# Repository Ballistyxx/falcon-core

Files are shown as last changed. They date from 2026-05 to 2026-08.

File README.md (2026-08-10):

# Falcon Core

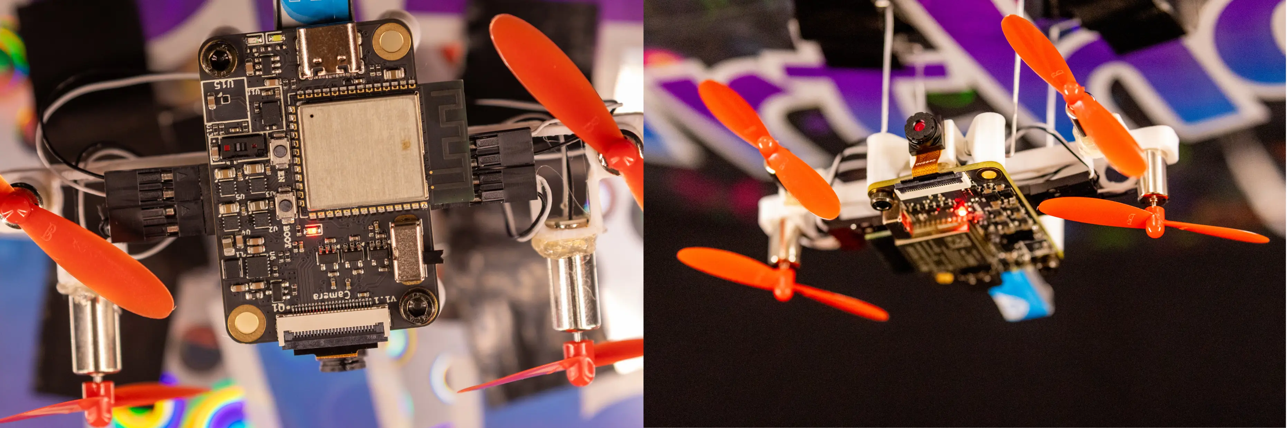
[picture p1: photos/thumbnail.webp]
Side-by-side images of the Falcon Core board


<!-- <table>
  <tr>
    <td><img src="photos/bottom-isometric-chassis.png" alt="Bottom isometric chassis" width="400"></td>
    <td><img src="photos/front-chassis.png" alt="Front chassis" width="400"></td>
  </tr>
</table> -->

A custom standalone ESP32-S3 flight controller for an indoor autonomous blimp. Successor to [Falcon Flight](https://github.com/PHS-SMCS/falcon-flight), redesigned from a Raspberry Pi Zero 2W HAT into a purpose-built 32×46mm 4-layer PCB.

Sponsored by [PCBWay](https://www.pcbway.com/).

## Specifications

- **MCU:** ESP32-S3-WROOM-1 (N8R8/N16R8) — dual-core LX7, Wi-Fi, BLE, 8MB PSRAM
- **Camera:** OV2640 via 24-pin 0.5mm FFC, 8-bit DVP interface
- **IMU:** BMI270 (6-axis accel/gyro, I2C)
- **Magnetometer:** MMC5633NJL (3-axis AMR, I2C, 1.62–3.6V)
- **ToF Sensor:** VL53L5CX (I2C)
- **Motor Drivers:** 4× DRV8212P bidirectional H-bridge
- **Battery Sensing:** Internal ADC (GPIO7)
- **Status LED:** Programmable red LED (GPIO48)
- **Board:** 32×46mm, 4-layer, matte black solder mask
- **Weight:** only 11 grams (excluding battery)

## Power

- **Battery:** BetaFPV 3.7V 300mAh 1S LiPo
- **Charging:** TP4057 via USB-C (5.1kΩ CC pull-downs)
- **Motor Power:** Direct battery feed to DRV8212P VM pins
- **Logic Isolation:** BLM18PG221SN1D ferrite bead between battery and logic rail
- **Regulators (ME6211 LDOs, SOT-23-5):**
  - 3.3V — ESP32-S3, sensors, VDDIO
  - 2.8V × 2 — OV2640 AVDD and DOVDD
  - 1.2V — OV2640 DVDD

## GPIO Assignment

| GPIO | Function |
|---|---|
| 1, 2 | SCCB (camera I2C — SIOD, SIOC) |
| 3 | M2_IN1 |
| 4 | M3_IN2 |
| 5 | M3_IN1 |
| 6 | M1_IN2 |
| 7 | BAT_ADC (battery voltage sensing) |
| 8, 18 | Main I2C bus (SDA, SCL) |
| 9, 10, 11, 12, 13, 14, 21, 40 | OV2640 DVP data bus (D8, D7, D6, D2, D5, D3, D4, D9) |
| 15 | M4_IN1 |
| 16 | M4_IN2 |
| 17 | M2_IN2 |
| 19, 20 | USB D−/D+ |
| 38 | Camera PCLK |
| 39 | Camera XCLK |
| 41 | HREF |
| 42 | VSYNC |
| 43, 44 | UART0 debug |
| 47 | M1_IN1 |
| 48 | Red LED (1kΩ to GND) |

Camera PWDN tied to GND, RESETB tied to 3.3V.

## I2C Bus

All sensors share the main I2C bus (GPIO8/18):

- BMI270 (accel/gyro)
- MMC5633NJL (magnetometer)
- VL53L5CX (time-of-flight)

Camera SCCB runs on a separate bus (GPIO1/2).

## Motor Layout

- 2× horizontal forward-facing motors (thrust)
- 1× downward-facing altitude motor (mounted below PCB on standoff)
- 1× TBD

## Firmware

Built with ESP-IDF. Custom PID stabilization (no ArduPilot). Communicates with a laptop over WebSocket for optical flow and AprilTag detection via OpenCV.

## License

See [LICENSE](LICENSE).

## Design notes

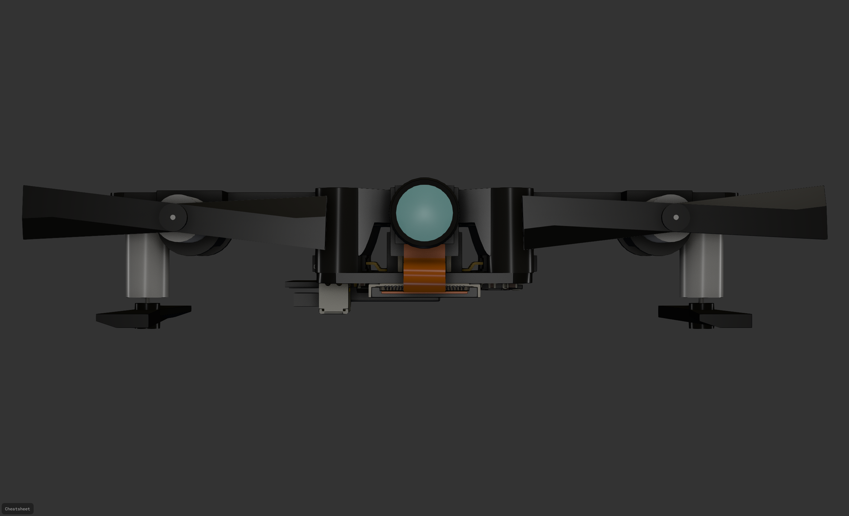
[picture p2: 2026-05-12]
photos/front-chassis.png

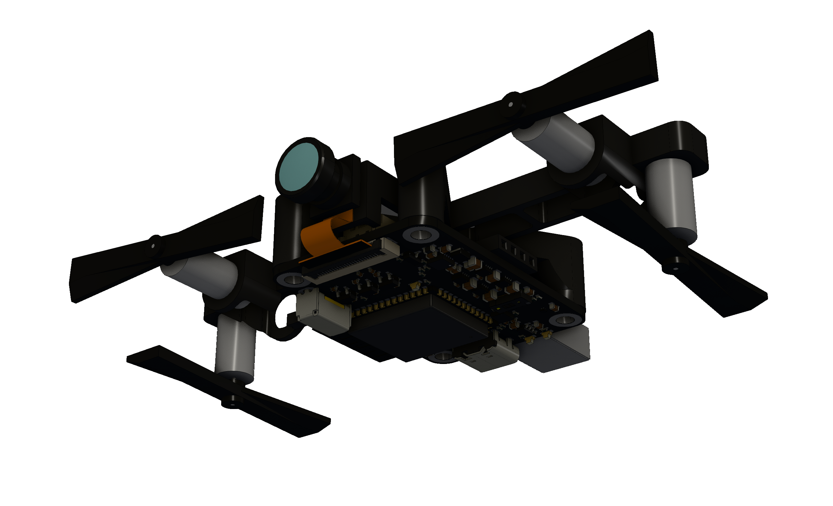
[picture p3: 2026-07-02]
photos/bottom-isometric-chassis.png

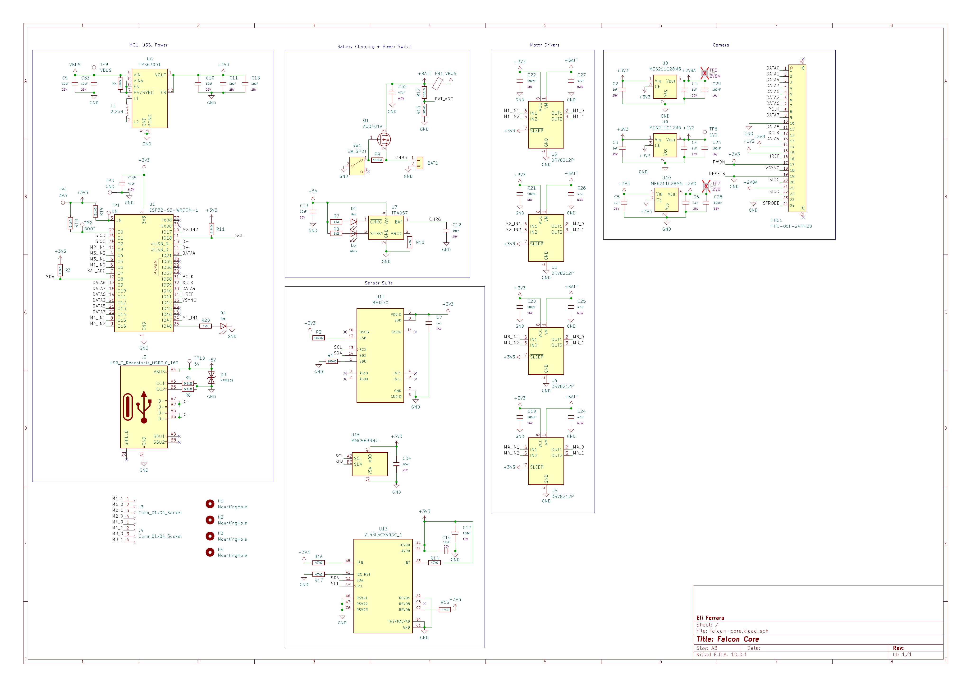
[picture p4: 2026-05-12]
PCB/schematic.png

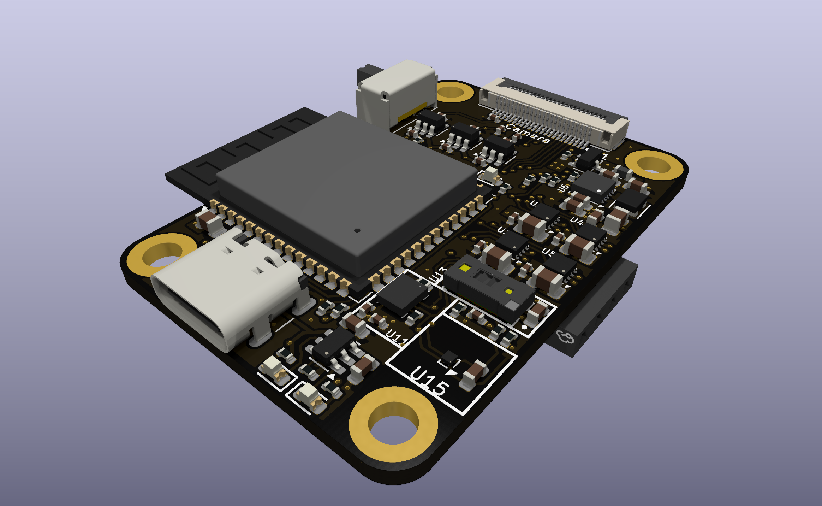
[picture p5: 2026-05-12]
photos/falcon-core.png

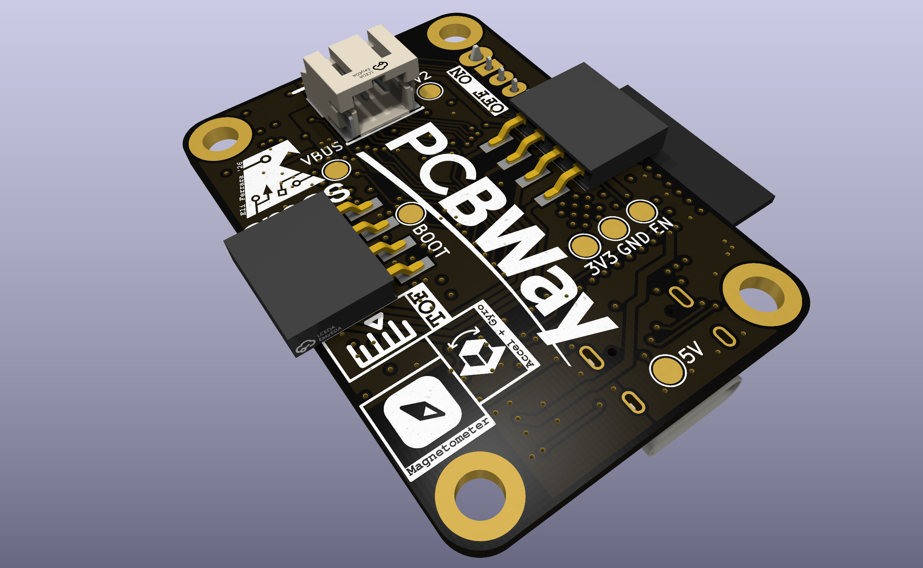
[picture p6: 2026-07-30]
photos/falcon-core-bottom-isometric.png

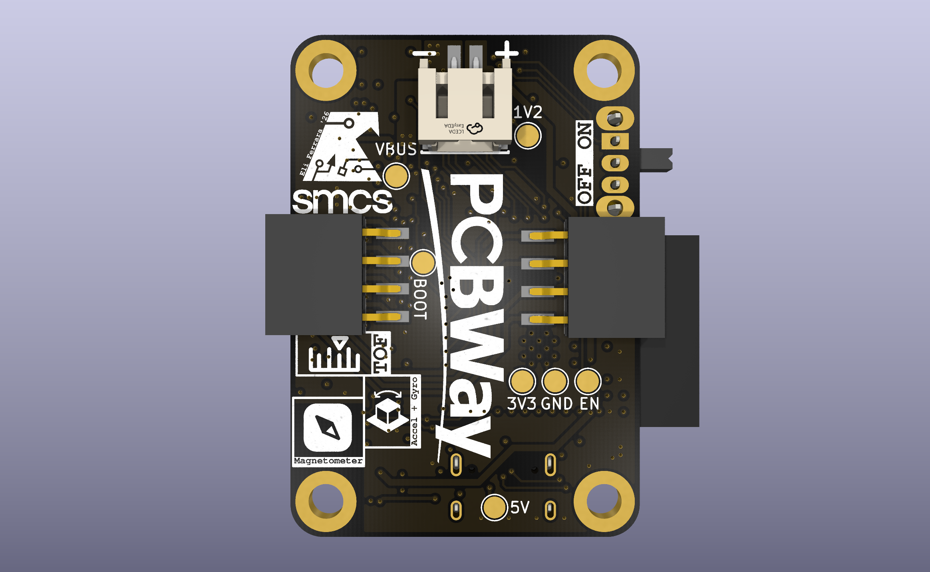
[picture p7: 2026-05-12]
photos/falcon-core-bottom.png

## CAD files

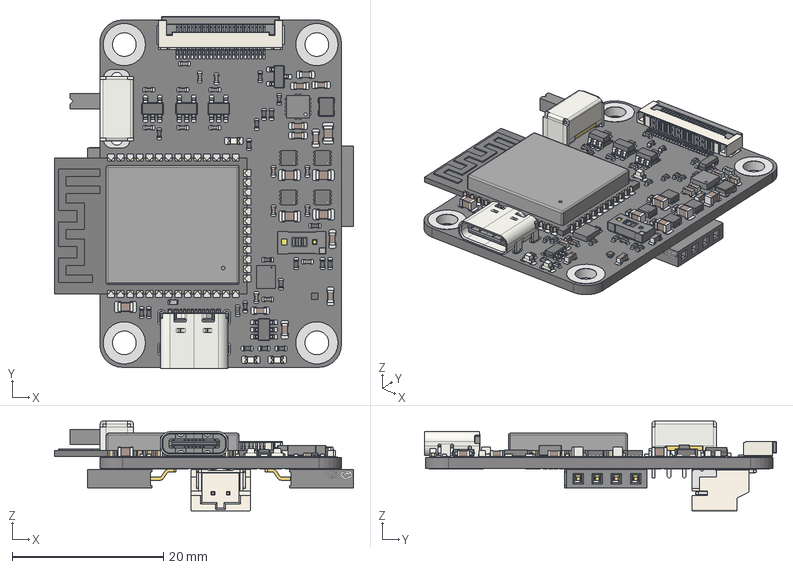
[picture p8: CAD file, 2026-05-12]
PCB/.step
39.6 x 46.7 x 11.9 mm
R_0402 x 20
SOT-23-5 x 3
C_0402 x 16
USB_C_Receptacle_GCT_USB4105-xx-A_16P_TopMnt_Horizontal
C_0805 x 6
TPS63001DRCR
C_0603 x 9
WSON-8-1EP_2x2mm_P0.5mm_EP0.9x1.6mm x 4
SOT-23
D_0603 x 3
BMI270_BOS
WLP-4_0.86x0.86mm_P0.4mm
FPC-SMD_24P-P0.50_FPC-05F-24PH20
VL53L5CXV0GC_1
ESP32-S3-WROOM-1
DFN1006-2L-RD
TSOT-23-6
SW_Slide_SPDT_Angled_CK_OS102011MA1Q
L_APV_ANR252010
L_0603_1608Metric
CONN-SMD_P2.00_S2B-PH-SM4-TB-LF-SN
CONN-SMD_4P-P2.54_HX-PM2.54-1X4PWT x 2
falcon-core_pad
falcon-core_PCB

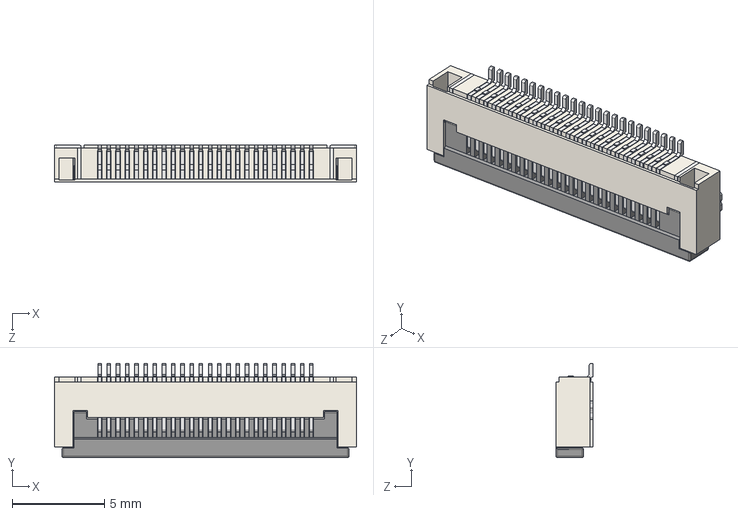
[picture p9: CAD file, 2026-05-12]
PCB/jlcpcb_lib/3dmodels/FPC-SMD_24P-P0.50_FPC-05F-24PH20.step
16.4 x 5.12 x 2.00 mm

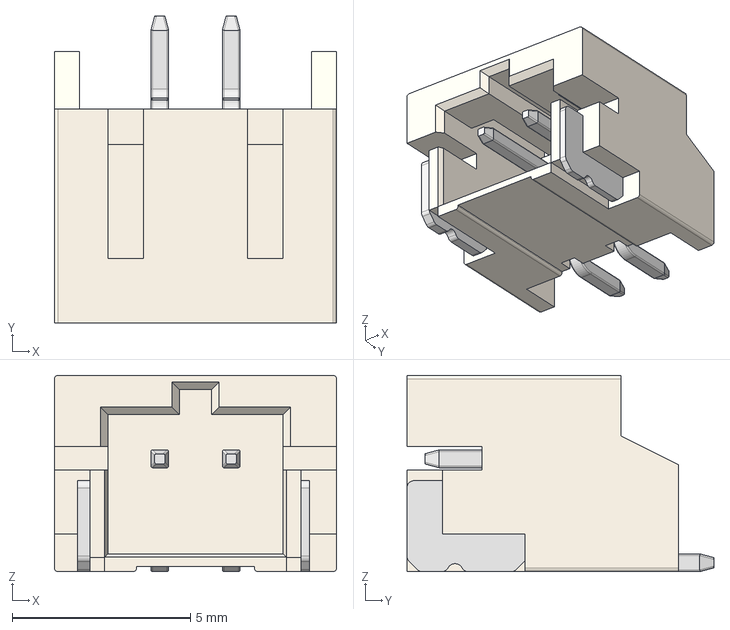
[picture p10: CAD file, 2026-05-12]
PCB/jlcpcb_lib/3dmodels/CONN-SMD_cleaned_v2.step
7.90 x 8.60 x 5.50 mm

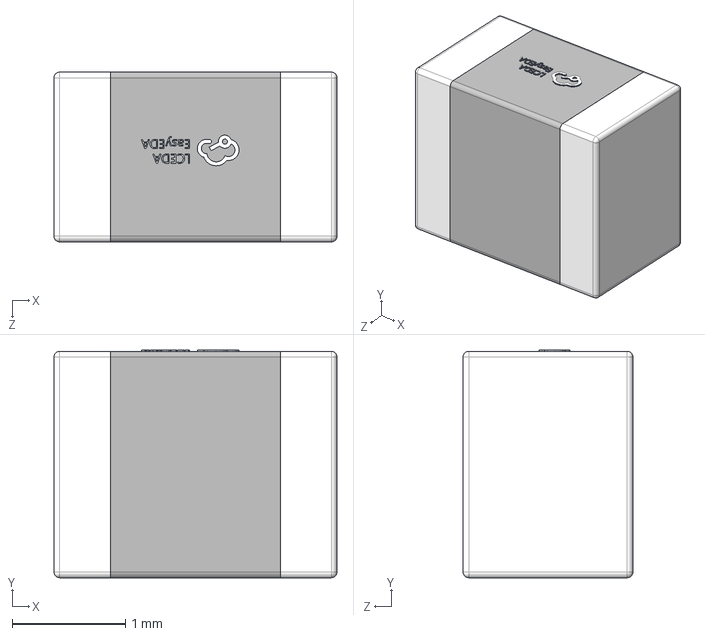
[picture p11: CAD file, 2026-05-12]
PCB/jlcpcb_lib/3dmodels/L1008.step
2.50 x 2.01 x 1.50 mm

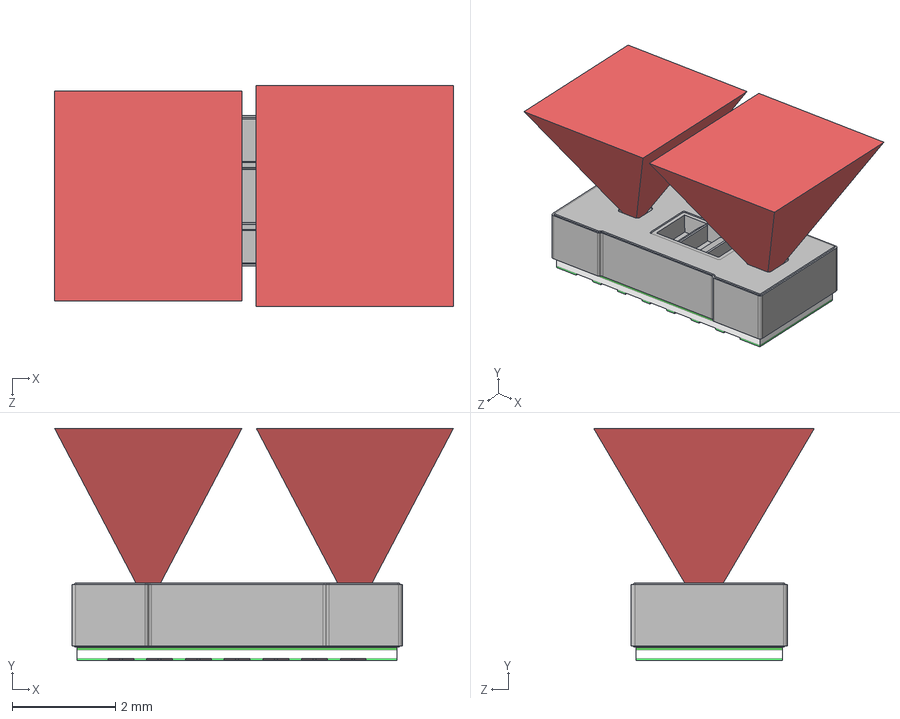
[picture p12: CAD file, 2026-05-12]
PCB/jlcpcb_lib/3dmodels/VL53L5 3D Model.step
7.72 x 4.50 x 4.28 mm
VL53L5 Module
VL53L5 Exclusion cones

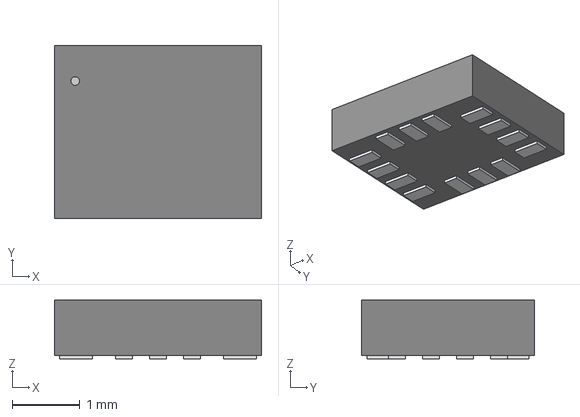
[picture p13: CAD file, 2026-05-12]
PCB/jlcpcb_lib/3dmodels/BMI270_BOS.step
3.05 x 2.54 x 0.866 mm

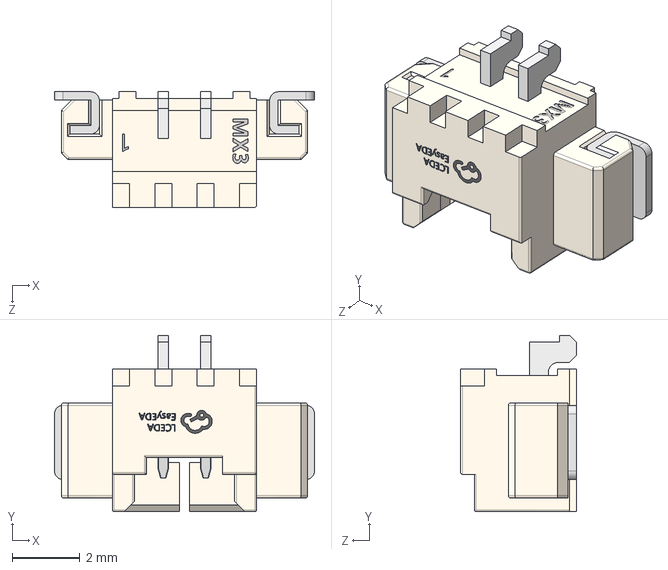
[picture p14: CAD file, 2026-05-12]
PCB/jlcpcb_lib/3dmodels/CONN-SMD_P1.25-H_1.25T-2PWT.step
7.65 x 5.19 x 3.40 mm

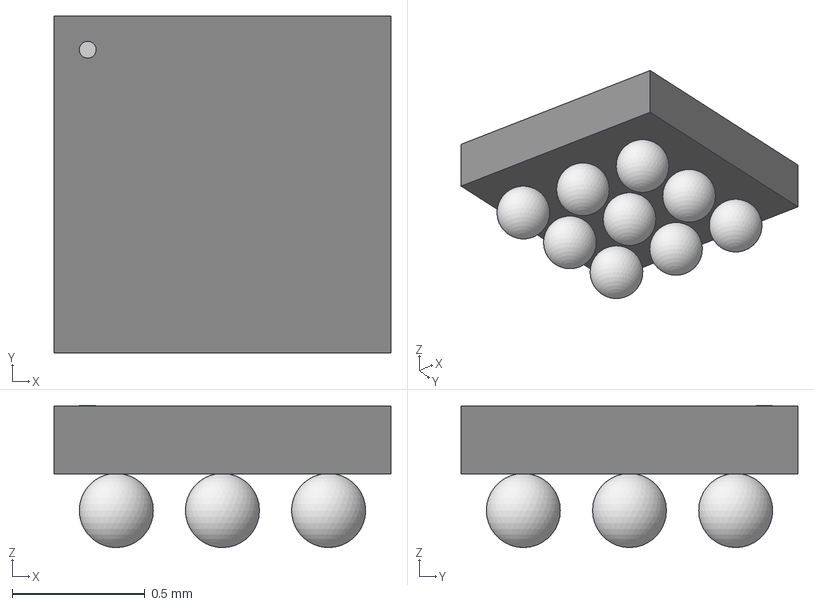
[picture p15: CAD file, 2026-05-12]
PCB/jlcpcb_lib/3dmodels/BGA9_BMM350_BOS.step
1.27 x 1.27 x 0.536 mm

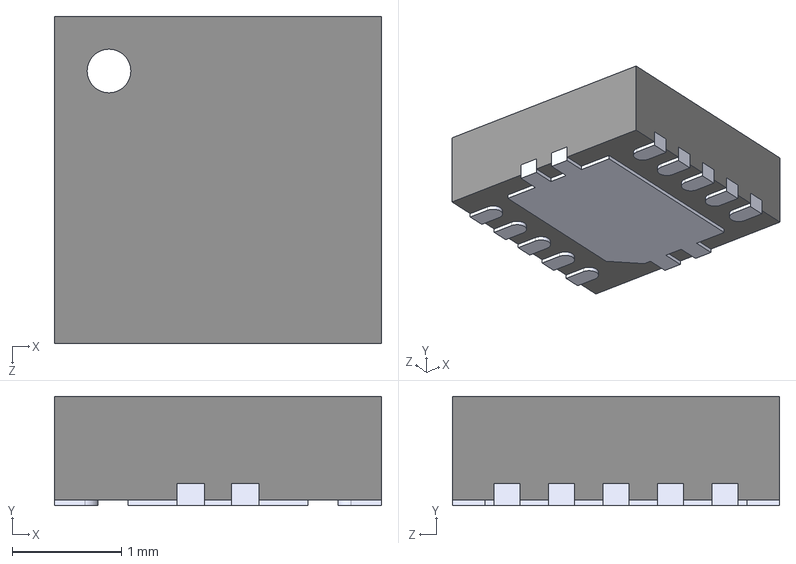
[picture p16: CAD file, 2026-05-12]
PCB/jlcpcb_lib/3dmodels/TPS63001DRCR.STEP
3.00 x 1.00 x 3.00 mm

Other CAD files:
PCB/jlcpcb_lib/3dmodels/CONN-SMD_P2.00_S2B-PH-SM4-TB-LF-SN.step

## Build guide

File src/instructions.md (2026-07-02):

# Falcon Core – Implementation Prompt

Build the firmware (ESP-IDF v5+, C) and web dashboard (HTML/CSS/JS, served locally) for an autonomous blimp flight controller. The ESP32-S3 streams camera video, reads sensors, runs motor control, and communicates with a laptop dashboard over WiFi. The dashboard provides live telemetry, a camera feed, and keyboard-based manual flight control.

---

## Hardware Overview

**MCU:** ESP32-S3-WROOM-1 (dual-core, 8MB flash, PSRAM via octal SPI)

**Confirmed GPIO Pinout:**

| Function | GPIO(s) | Notes |
|---|---|---|
| I2C SDA | IO8 | Shared bus: IMU, mag, ToF |
| I2C SCL | IO18 | |
| Camera SCCB SDA  | IO1 | Separate I2C for OV2640 config |
| Camera SCCB SCL  | IO2 | |
| Camera DVP data  | IO9(D8), IO10(D7), IO11(D6), IO12(D2), IO13(D5), IO14(D3), IO21(D4), IO40(D9) | |
| Camera HREF | IO41 | |
| Camera VSYNC | IO42 | |
| Camera PCLK | IO38 | |
| Camera XCLK | IO39 | Generate 20MHz via LEDC |
| Motor 1 IN1/IN2  | IO17 / IO6 | Horizontal left |
| Motor 2 IN1/IN2  | IO3 / IO47 | Horizontal right |
| Motor 3 IN1/IN2  | IO5 / IO4 | Vertical (altitude) |
| Motor 4 IN1/IN2  | IO15 / IO16 | Reserved (future use) |
| Battery ADC | IO7 | Resistive divider, ADC1 channel|
| Status LED | IO48 | Red LED, 1kΩ to GND |
| USB D-/D+ | IO19 / IO20 | USB-Serial-JTAG |
| UART0 TX/RX | IO43 / IO44 | Debug output |

**Motor Drivers:** 4× DRV8212P (bidirectional H-bridge). Each has IN1 and IN2 pins. PWM on IN1 with IN2 LOW = forward. PWM on IN2 with IN1 LOW = reverse. Both LOW = coast. Both HIGH = brake. Use ESP-IDF LEDC PWM at 20kHz.

**Sensors (all on shared I2C bus at IO8/IO18):**

| Sensor | Type | I2C Address | Key Details |
|---|---|---|---|
| BMI270 | 6-axis IMU | 0x68 | Accel + gyro. Requires config load on init. |
| MMC5633NJL | 3-axis magnetometer | 0x30 | SET/RESET for offset, continuous mode. |
| VL53L5CX | Multizone ToF | 0x29 | 8×8 ranging grid, I2C. Use ST's ULD driver. |

**Camera:** OV2640 via DVP (parallel interface). PWDN tied low, RESETB tied high. 24-pin 0.5mm FFC. Use `esp_camera` component from Espressif's registry.

---

## Firmware Architecture (ESP-IDF, C)

### WiFi

Connect in STA mode to a configured network (SSID/password stored in `sdkconfig` or hardcoded for now). Log the assigned IP address on boot so the user knows where to point the dashboard.

### HTTP + WebSocket Server

Use `esp_http_server`. Register these endpoints:

- `GET /stream` — MJPEG stream. Each connected client receives `multipart/x-mixed-replace` with boundary-delimited JPEG frames from the camera. Multiple simultaneous clients must be supported.
- `GET /ws` — WebSocket upgrade. Single endpoint for all bidirectional real-time data.

### WebSocket Protocol

Use JSON messages. Every message has a `"type"` field.

**ESP32 → Dashboard (telemetry, ~20Hz):**

```json
{
  "type": "telemetry",
  "ts": 123456,
  "imu": {
    "ax": 0.01, "ay": -0.02, "az": 9.78,
    "gx": 0.5, "gy": -0.3, "gz": 0.1
  },
  "mag": { "x": 25.3, "y": -10.1, "z": 42.0, "heading": 127.5 },
  "tof": { "distance_mm": 1200 },
  "battery": { "voltage": 3.85, "percent": 72 },
  "attitude": { "roll": 1.2, "pitch": -0.5, "yaw": 127.5 },
  "motors": { "m1": 0, "m2": 0, "m3": 0, "m4": 0 }
}
```

**Dashboard → ESP32 (commands):**

```json
{ "type": "motor_cmd", "m1": 0.5, "m2": 0.5, "m3": 0.0, "m4": 0.0 }
```

Motor values are floats from -1.0 (full reverse) to +1.0 (full forward). The firmware maps these to LEDC duty cycle and direction on IN1/IN2.

**Future extension:** A `"type": "velocity_cmd"` message will be added later for optical-flow-based velocity control. Design the command dispatch so new message types can be added without restructuring.

### FreeRTOS Tasks

| Task | Core | Priority | Rate | Description |
|---|---|---|---|---|
| `sensor_task` | 0 | 5 | 50Hz | Read BMI270 (accel+gyro) and MMC5633NJL (mag) via I2C. |
| `fusion_task` | 0 | 5 | 50Hz | Madgwick or complementary filter. Compute attitude + heading.  |
| `motor_task` | 0 | 6 | 50Hz | Read latest command from shared state, set LEDC duty cycles. |
| `tof_task` | 0 | 4 | 10Hz | Read VL53L5CX ranging data (center zone distance). |
| `battery_task` | 0 | 3 | 1Hz | Read ADC on IO7, compute voltage from divider ratio. |
| `camera_task` | 1 | 5 | — | Capture frames via `esp_camera`, push to frame buffer. |
| `telemetry_task` | 0 | 4 | 20Hz | Serialize shared state to JSON, send to all WS clients. |
| HTTP server | any  | 5 | event  | Handles `/stream` and `/ws`. Started once at init. |

### Shared State

A single struct protected by a FreeRTOS mutex. All tasks read/write through short critical sections (copy in, copy out).

```c
typedef struct {
    // Sensor data (written by sensor_task)
    float accel[3];
    float gyro[3];
    float mag[3];

    // Derived data (written by fusion_task)
    float roll, pitch, yaw;
    float heading_deg;

    // ToF (written by tof_task)
    uint16_t altitude_mm;

    // Battery (written by battery_task)
    float battery_voltage;
    uint8_t battery_percent;

    // Motor commands (written by WS receive handler)
    float motor_cmd[4];     // -1.0 to +1.0

    // Motor actual output (written by motor_task)
    float motor_output[4];
} falcon_state_t;
```

### Sensor Implementation Notes

**BMI270:** Requires a microcode config file upload after power-on before it produces data. The config binary is available from Bosch's BMI270 driver repo. Use burst I2C writes. After config, set accel to ±2g and gyro to ±500°/s at 100Hz ODR.

**MMC5633NJL:** Issue a SET then RESET command to initialize. Configure continuous measurement mode at 50Hz with auto SET/RESET enabled. Read XYZ registers. For now, heading = `atan2(y, x)` converted to degrees (tilt compensation will come later with fusion). Do not attempt calibration yet — just output raw values and heading.

**VL53L5CX:** Use ST's Ultra Lite Driver (ULD). Initialize, set resolution to 4×4 or 8×8, start ranging in continuous mode. For telemetry, report the center zone distance as altitude. The full zone grid will be used later.

**Battery ADC:** Use `adc_oneshot` API on ADC1. Apply the resistor divider ratio to convert raw reading to actual battery voltage. Map voltage to percentage using a simple linear approximation (3.0V = 0%, 4.2V = 100%).

### Motor Control

Initialize 4 LEDC channels at 20kHz. For each motor, two GPIO pins (IN1, IN2) map to forward and reverse:

```
if cmd > 0:  IN1 = PWM at |cmd| duty, IN2 = LOW   (forward)
if cmd < 0:  IN1 = LOW, IN2 = PWM at |cmd| duty    (reverse)
if cmd == 0: IN1 = LOW, IN2 = LOW                   (coast)
```

Duty cycle = `|cmd| * max_duty`. Clamp to a configurable maximum (start at 50% for safety during testing).

### Status LED

Blink patterns on IO48 to indicate state:
- Slow blink (1Hz): Connecting to WiFi
- Solid on: Connected, running
- Fast blink (5Hz): Error state

### sdkconfig.defaults

```
CONFIG_IDF_TARGET="esp32s3"
CONFIG_ESP_CONSOLE_USB_SERIAL_JTAG=y
CONFIG_ESPTOOLPY_FLASHMODE_DIO=y
CONFIG_ESPTOOLPY_FLASHFREQ_80M=y
CONFIG_ESPTOOLPY_FLASHSIZE_8MB=y
CONFIG_ESP_WIFI_SSID="Home-TMobile5g"
CONFIG_ESP_WIFI_PASSWORD="PSU4LIFE!"
CONFIG_HTTPD_MAX_REQ_HDR_LEN=1024
CONFIG_HTTPD_WS_SUPPORT=y
```

### Project Structure

```
src/
├── CMakeLists.txt
├── sdkconfig.defaults
├── main/
│   ├── CMakeLists.txt
│   ├── main.c              # app_main: init all subsystems, start tasks
│   ├── wifi.c / wifi.h      # STA connection, event handling
│   ├── server.c / server.h  # HTTP + WS server, MJPEG streaming
│   ├── camera.c / camera.h  # esp_camera init and frame capture
│   ├── sensors.c / sensors.h # BMI270, MMC5633NJL, VL53L5CX drivers
│   ├── fusion.c / fusion.h  # Attitude estimation (Madgwick filter)
│   ├── motors.c / motors.h  # LEDC PWM setup and motor command execution
│   ├── battery.c / battery.h # ADC reading, voltage/percent calculation
│   ├── state.c / state.h    # falcon_state_t definition, mutex helpers
│   └── led.c / led.h        # Status LED blink patterns
```

---

## Web Dashboard (HTML/CSS/JS)

A single `index.html` file served locally on the laptop (not from the ESP32). It connects to the blimp over the local network.

### Connection

On load, prompt for or use a hardcoded blimp IP. Open:
- WebSocket to `ws://<ip>/ws` for telemetry and commands.
- `<img>` tag with `src="http://<ip>/stream"` for the MJPEG video feed.

### Layout

A single-page dashboard with these sections:

1. **Camera feed** — large, dominant. The MJPEG `<img>` element. Aspect ratio 4:3 or 16:9 depending on camera resolution.

2. **Compass** — a circular compass rose rendered in SVG or canvas. The needle rotates to show `heading_deg` from telemetry. Display heading in degrees numerically below it. Cardinal directions (N/S/E/W) labeled around the ring.

3. **Attitude indicator** — show roll and pitch visually (an artificial horizon or simple tilt bars). Yaw can share the compass.

4. **Sensor readouts** — a panel showing:
   - Battery voltage and percentage (with a colored bar: green > 50%, yellow 20-50%, red < 20%)
   - Altitude (ToF distance in mm or cm)
   - Raw accelerometer XYZ
   - Raw gyroscope XYZ
   - Raw magnetometer XYZ
   - Motor outputs M1–M4 (as bars or values)

5. **Connection status** — indicator showing WebSocket state (connected/disconnected/reconnecting).

6. **Controls legend** — small reference showing the WASD/QE key bindings.

### Keyboard Controls (WASD/QE)

Capture `keydown` and `keyup` events. While a key is held, send the corresponding motor command at 10Hz. On key release, send zero for that axis.

**Key mapping (differential thrust for translation + yaw):**

| Key | Action | Motor effect |
|-----|---|---|
| W | Forward | M1 = +throttle, M2 = +throttle (both horizontal fwd)  |
| S | Backward | M1 = -throttle, M2 = -throttle (both horizontal rev)  |
| A | Yaw left | M1 = -throttle, M2 = +throttle (differential) |
| D | Yaw right | M1 = +throttle, M2 = -throttle (differential) |
| Q | Descend | M3 = -throttle (vertical motor down) |
| E | Ascend | M3 = +throttle (vertical motor up) |

Throttle magnitude is a fixed value (start at 0.4). Multiple keys can be held simultaneously — sum the contributions per motor and clamp to [-1, 1]. M4 is always 0 for now.

Send commands as: `{ "type": "motor_cmd", "m1": 0.4, "m2": 0.4, "m3": 0.0, "m4": 0.0 }`

When no keys are held, send `{ "type": "motor_cmd", "m1": 0, "m2": 0, "m3": 0, "m4": 0 }` once, then stop sending.

### Telemetry Handling

Parse incoming `"type": "telemetry"` messages. Update all dashboard elements at the rate they arrive (~20Hz). Use `requestAnimationFrame` for smooth compass/attitude animation. Display a "stale data" warning if no telemetry arrives for >2 seconds.

### Reconnection

If the WebSocket drops, attempt reconnection every 3 seconds. Show connection state in the status indicator. The MJPEG `<img>` will stall on disconnect — provide a reload button or auto-retry via `onerror`.

### Styling

Dark theme. Monospace font for numeric readouts. The dashboard should be functional and readable, not flashy. Minimal dependencies — vanilla JS, no frameworks. CSS grid or flexbox for layout.

---

## What NOT to Implement Yet

- Optical flow (will be a separate Python script connecting to the same WebSocket later)
- Magnetometer calibration (raw values only for now)
- Tilt-compensated heading (use simple atan2 for now)
- Autonomous flight modes
- PID controllers
- AprilTag detection
- NVS storage for calibration data
- OTA firmware updates

Design all interfaces (WebSocket protocol, shared state struct, task architecture) so these can be added without restructuring existing code.

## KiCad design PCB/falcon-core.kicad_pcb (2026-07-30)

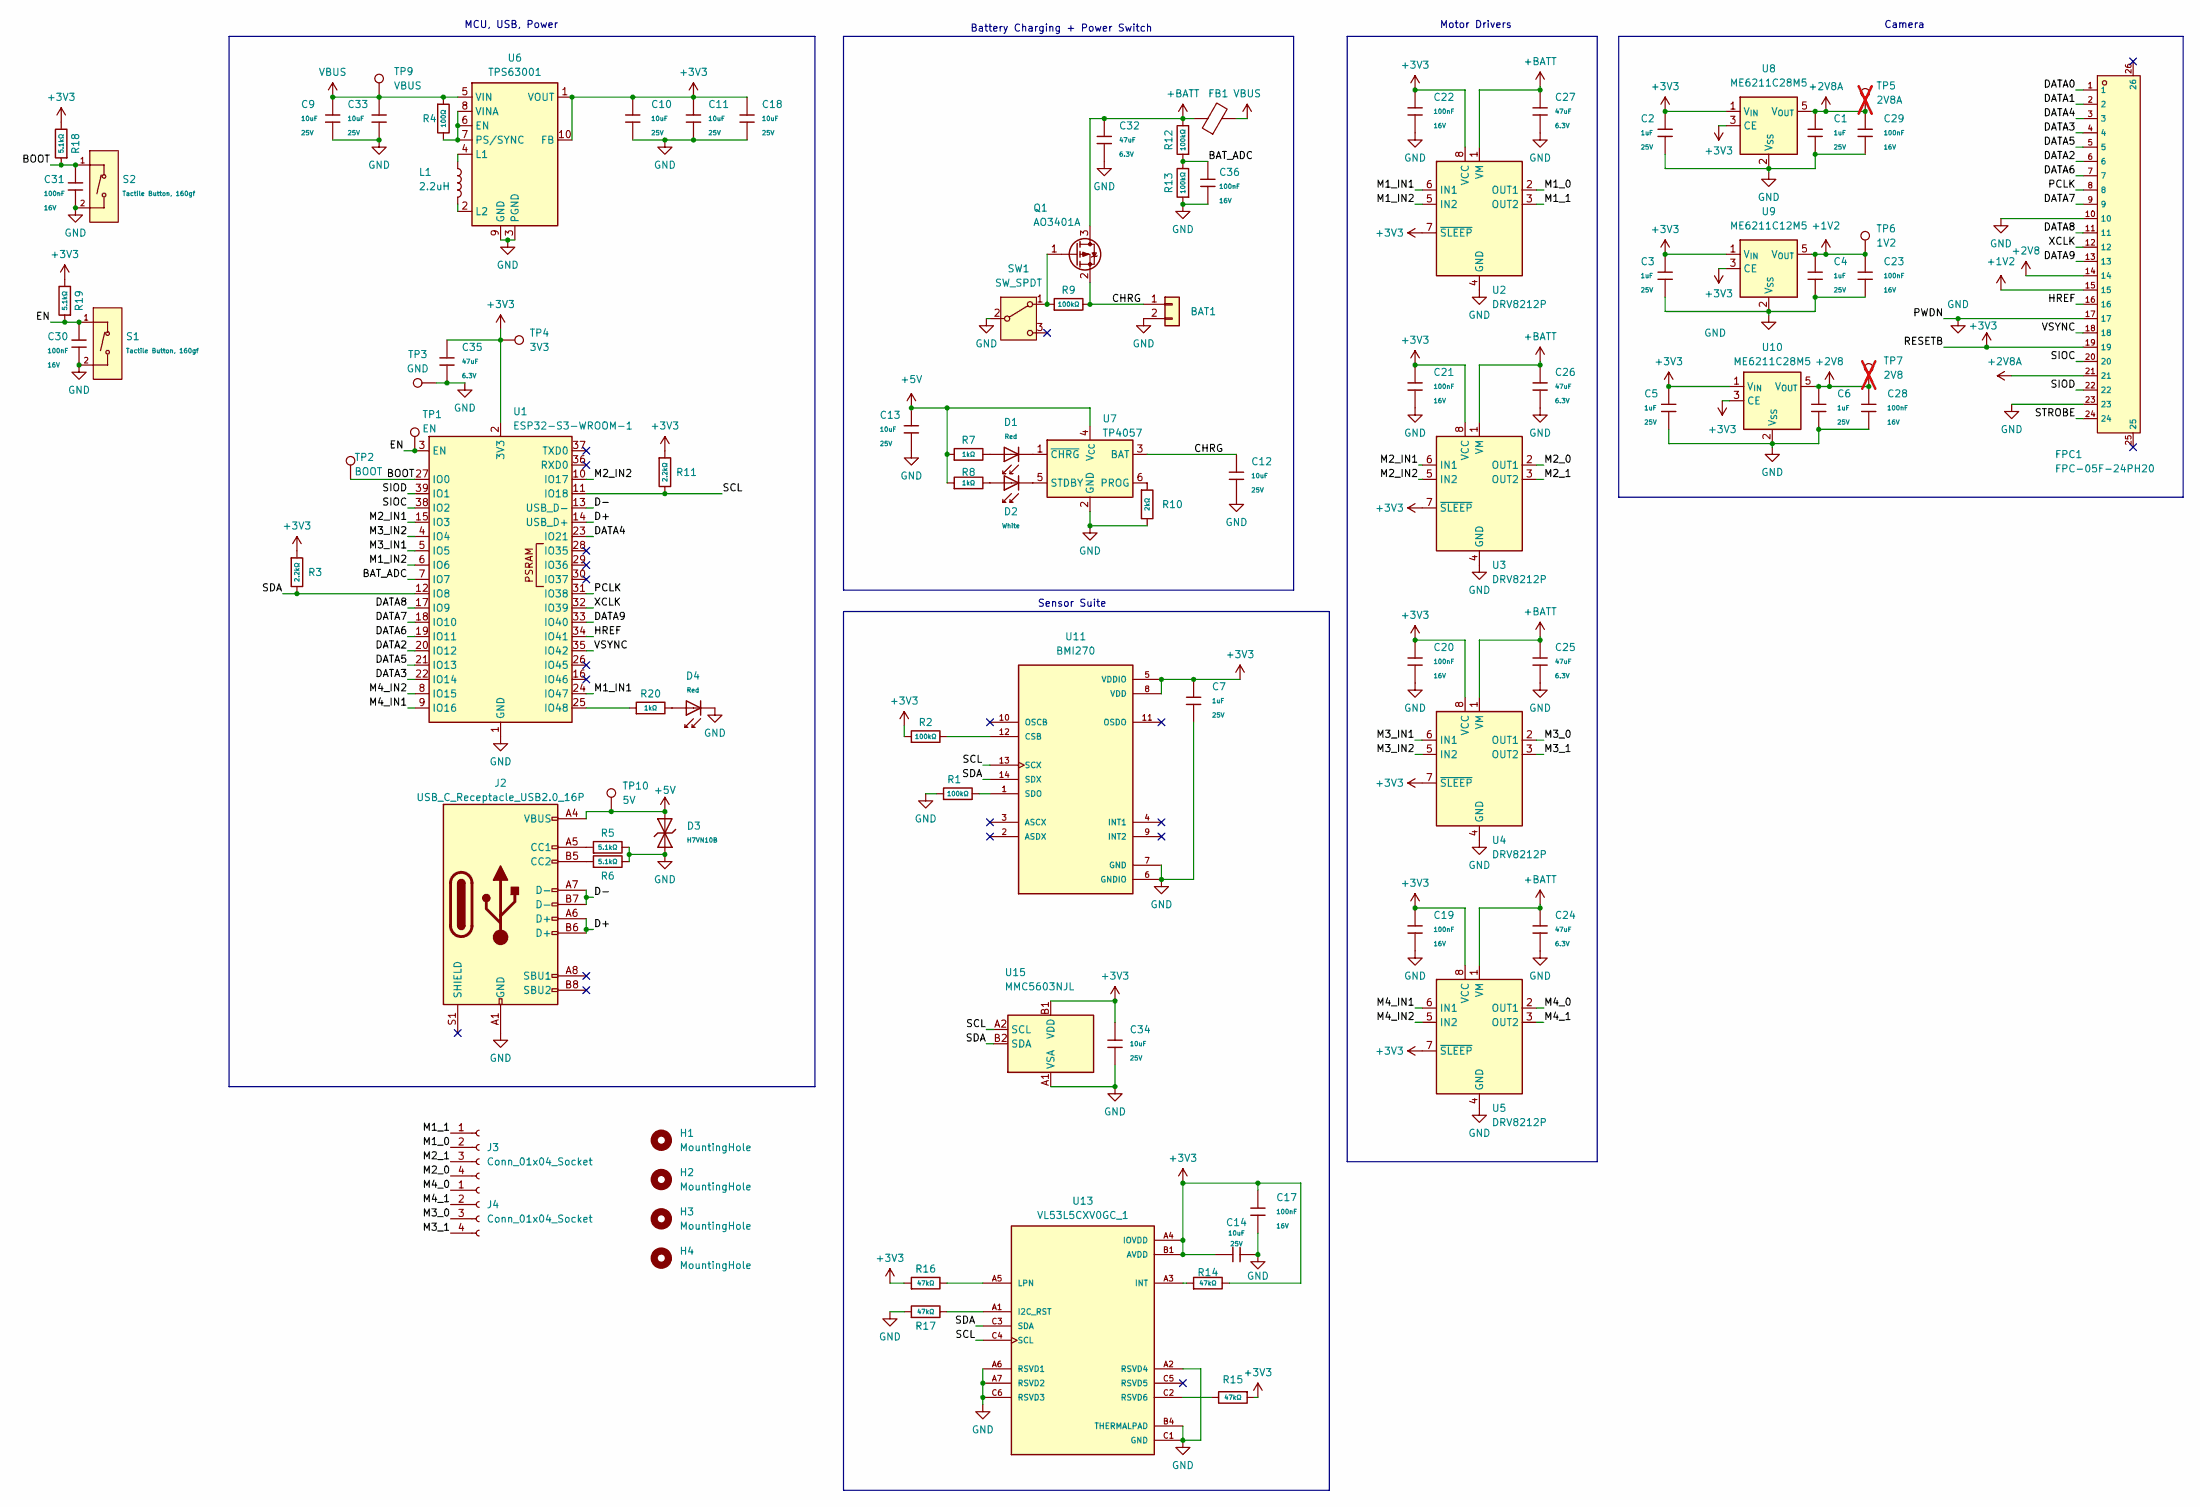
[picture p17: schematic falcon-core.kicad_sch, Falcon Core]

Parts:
BAT1: Conn_01x02; CONN-SMD_2P-P2.00_WF-1F200A2P; LCSC C23397052
C1, C2, C3, C4, C5, C6, C7: 1uF; C_0402; Voltage Rated 25V; Tolerance ±10%; Part CL05A105KA5NQNC; LCSC C52923
C9, C10, C11, C12, C13, C14, C18, C33, C34: 10uF; C_0603; Voltage Rated 25V; Tolerance ±20%; Part CL10A106MA8NRNC; LCSC C96446
C17, C19, C20, C21, C22, C23, C28, C29, C30, C31, C36: 100nF; C_0402; Voltage Rated 16V; Tolerance ±10%; Part CL05B104KO5NNNC; LCSC C1525
C24, C25, C26, C27, C32, C35: 47uF; C_0805; Voltage Rated 6.3V; Tolerance ±20%; Part CL21A476MQYNNNE; LCSC C16780
D1, D4: Red; D_0603; Part KT-0603R; LCSC C2286
D2: White; D_0603; Part KT-0603W; LCSC C2290
D3: H7VN10B; D_DFN1006-2L; Part H7VN10B; LCSC C20615788
FB1: FerriteBead; L_0603_1608Metric; LCSC Part Number C80165
FPC1: FPC-05F-24PH20; FPC-SMD_24P-P0.50_FPC-05F-24PH20; LCSC C2856805
H1, H2, H3, H4: MountingHole; MountingHole_3.2mm_M3_DIN965_Pad
J2: USB_C_Receptacle_USB2.0_16P; USB_C_Receptacle_GCT_USB4105-xx-A_16P_TopMnt_Horizontal; LCSC C393939
J3, J4: Conn_01x04_Socket; CONN-SMD_4P-P2.54_HX-PM2.54-1X4PWT; LCSC C46061768
L1: 2.2uH; L_APV_ANR252010; LCSC C5349606
Q1: AO3401A; SOT-23; LCSC C15127
R1, R2, R9, R12, R13: 100kΩ; R_0402; Overload Voltage (Max) 50V; Tolerance ±1%; Part 0402WGF1003TCE; LCSC C25741
R3, R11: 2.2kΩ; R_0402; Overload Voltage (Max) 50V; Tolerance ±1%; Part 0402WGF2201TCE; LCSC C25879
R4: 100Ω; R_0402; Overload Voltage (Max) 50V; Tolerance ±1%; Part 0402WGF1000TCE; LCSC C25076
R5, R6, R18, R19: 5.1kΩ; R_0402; Overload Voltage (Max) 50V; Tolerance ±1%; Part 0402WGF5101TCE; LCSC C25905
R7, R8, R20: 1kΩ; R_0402; Overload Voltage (Max) 50V; Tolerance ±1%; Part 0402WGF1001TCE; LCSC C11702
R10: 2kΩ; R_0402; Overload Voltage (Max) 50V; Tolerance ±1%; Part 0402WGF2001TCE; LCSC C4109
R14, R15, R16, R17: 47kΩ; R_0402; Overload Voltage (Max) 50V; Tolerance ±1%; Part 0402WGF4702TCE; LCSC C25792
S1, S2: Tactile Button, 160gf; SW_TS-1088-AR02016; Voltage Rating (Dc) 12V; Part TS-1088-AR02016; LCSC C720477
SW1: SW_SPDT; SW_Slide_SPDT_Angled_CK_OS102011MA1Q; LCSC C431547
TP1: EN; TestPoint_Pad_D2.0mm
TP2: BOOT; TestPoint_Pad_D2.0mm
TP3: GND; TestPoint_Pad_D2.0mm
TP4: 3V3; TestPoint_Pad_D2.0mm
TP5: 2V8A; TestPoint_Pad_D2.0mm; not fitted
TP6: 1V2; TestPoint_Pad_D2.0mm
TP7: 2V8; TestPoint_Pad_D2.0mm; not fitted
TP9: VBUS; TestPoint_Pad_D2.0mm
TP10: 5V; TestPoint_Pad_D2.0mm
U1: ESP32-S3-WROOM-1; LCSC C2913202
U2, U3, U4, U5: DRV8212P; WSON-8-1EP_2x2mm_P0.5mm_EP0.9x1.6mm_ThermalVias; LCSC C5208051
U6: TPS63001; Texas_DRC0010J_ThermalVias; LCSC C28060
U7: TP4057; TSOT-23-6; LCSC C12044
U8, U10: ME6211C28M5; SOT-23-5; LCSC C53099
U9: ME6211C12M5; SOT-23-5; LCSC C236672
U11: BMI270; XDCR_BMI270; LCSC C2836813
U13: VL53L5CXV0GC_1; XDCR_VL53L5CXV0GC_1; PARTREV 13; LCSC C3178303
U15: MMC5603NJL; WLP-4_0.86x0.86mm_P0.4mm; LCSC C404328

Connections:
+1V2: C4.1, C23.2, FPC1.15, TP6.1 (1_1), U9.5 (V_{OUT})
+2V8: C6.1, C28.2, FPC1.14, TP7.1, U10.5 (V_{OUT})
+2V8A: C1.1, C29.2, FPC1.21, TP5.1, U8.5 (V_{OUT})
+5V: C13.1, D3.2, J2.A4 (VBUS), J2.A9 (VBUS), J2.B4 (VBUS), J2.B9 (VBUS), R7.1, R8.1, TP10.1 (1_1), U7.4 (V_{CC})
+BATT: C24.1, C25.1, C26.1, C27.1, C32.1, FB1.1, Q1.3 (D), R12.2, U2.1 (VM), U3.1 (VM), U4.1 (VM), U5.1 (VM)
/BAT_ADC: C36.1, R12.1, R13.2, U1.7 (IO7)
/BOOT: C31.1, R18.1, S2.1 (A), TP2.1 (1_1), U1.27 (IO0)
/CHRG: BAT1.1, C12.1, Q1.2 (S), R9.2, U7.3 (BAT)
/D+: J2.A6 (D+), J2.B6 (D+), U1.14 (USB_D+)
/D-: J2.A7 (D-), J2.B7 (D-), U1.13 (USB_D-)
/DATA0: FPC1.1
/DATA1: FPC1.2
/DATA2: FPC1.6, U1.20 (IO12)
/DATA3: FPC1.4, U1.22 (IO14)
/DATA4: FPC1.3, U1.23 (IO21)
/DATA5: FPC1.5, U1.21 (IO13)
/DATA6: FPC1.7, U1.19 (IO11)
/DATA7: FPC1.9, U1.18 (IO10)
/DATA8: FPC1.11, U1.17 (IO9)
/DATA9: FPC1.13, U1.33 (IO40)
/HREF: FPC1.16, U1.34 (IO41)
/M1_0: J3.2, U2.2 (OUT1)
/M1_1: J3.1, U2.3 (OUT2)
/M1_IN1: U1.24 (IO47), U2.6 (IN1)
/M1_IN2: U1.6 (IO6), U2.5 (IN2)
/M2_0: J3.4, U3.2 (OUT1)
/M2_1: J3.3, U3.3 (OUT2)
/M2_IN1: U1.15 (IO3), U3.6 (IN1)
/M2_IN2: U1.10 (IO17), U3.5 (IN2)
/M3_0: J4.3, U4.2 (OUT1)
/M3_1: J4.4, U4.3 (OUT2)
/M3_IN1: U1.5 (IO5), U4.6 (IN1)
/M3_IN2: U1.4 (IO4), U4.5 (IN2)
/M4_0: J4.1, U5.2 (OUT1)
/M4_1: J4.2, U5.3 (OUT2)
/M4_IN1: U1.9 (IO16), U5.6 (IN1)
/M4_IN2: U1.8 (IO15), U5.5 (IN2)
/PCLK: FPC1.8, U1.31 (IO38)
/SCL: R11.2, U1.11 (IO18), U11.13 (SCX), U13.C4 (SCL), U15.A2 (SCL)
/SDA: R3.2, U1.12 (IO8), U11.14 (SDX), U13.C3 (SDA), U15.B2 (SDA)
/SIOC: FPC1.20, U1.38 (IO2)
/SIOD: FPC1.22, U1.39 (IO1)
/STROBE: FPC1.24
/VSYNC: FPC1.18, U1.35 (IO42)
/XCLK: FPC1.12, U1.32 (IO39)
GND: BAT1.2, C1.2, C2.2, C3.2, C4.2, C5.2, C6.2, C7.2, C9.2, C10.2, C11.2, C12.2, C13.2, C14.2, C17.2, C18.2, C19.1, C20.1, C21.1, C22.1, C23.1, C24.2, C25.2, C26.2, C27.2, C28.1, C29.1, C30.2, C31.2, C32.2, C33.2, C34.1, C35.2, C36.2, D3.1, D4.1, FPC1.10, FPC1.17, FPC1.23, J2.A1 (GND), J2.A12 (GND), J2.B1 (GND), J2.B12 (GND), R1.1, R5.2, R6.2, R10.2, R13.1, R17.1, S1.2 (B), S2.2 (B), SW1.2 (B), TP3.1 (1_1), U1.1 (GND), U1.40 (GND), U1.41 (GND), U2.4 (GND), U2.9 (GND), U3.4 (GND), U3.9 (GND), U4.4 (GND), U4.9 (GND), U5.4 (GND), U5.9 (GND), U6.3 (PGND), U6.9 (GND), U6.11 (PGND), U7.2 (GND), U8.2 (V_{SS}), U9.2 (V_{SS}), U10.2 (V_{SS}), U11.6 (GNDIO), U11.7 (GND), U13.A2 (RSVD4), U13.A6 (RSVD1), U13.A7 (RSVD2), U13.B4 (THERMALPAD), U13.C1 (GND), U13.C6 (RSVD3), U13.C7 (GND), U15.A1 (VSA); also elsewhere on the board
unnamed: D1.2, R7.2
unnamed: D2.2, R8.2
unnamed: D4.2, R20.2
unnamed: J2.A5 (CC1), R5.1
unnamed: J2.B5 (CC2), R6.1
unnamed: Q1.1 (G), R9.1, SW1.1 (A)
unnamed: R20.1, U1.25 (IO48)
unnamed: R4.2, U6.6 (EN), U6.7 (PS/SYNC), U6.8 (VINA)
unnamed: L1.1, U6.4 (L1)
unnamed: L1.2, U6.2 (L2)
unnamed: R10.1, U7.6 (PROG)
unnamed: D2.1, U7.5 (STDBY)
unnamed: D1.1, U7.1 (~CHRG)
unnamed: R2.2, U11.12 (CSB)
unnamed: R1.2, U11.1 (SDO)
unnamed: R17.2, U13.A1 (I2C_RST)
unnamed: R14.1, U13.A3 (INT)
unnamed: R16.2, U13.A5 (LPN)
unnamed: R15.2, U13.C2 (RSVD6)
VBUS: C9.1, C33.1, FB1.2, R4.1, TP9.1 (1_1), U6.5 (VIN)

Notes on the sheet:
Battery Charging + Power Switch
Sensor Suite
MCU, USB, Power
Camera
Motor Drivers

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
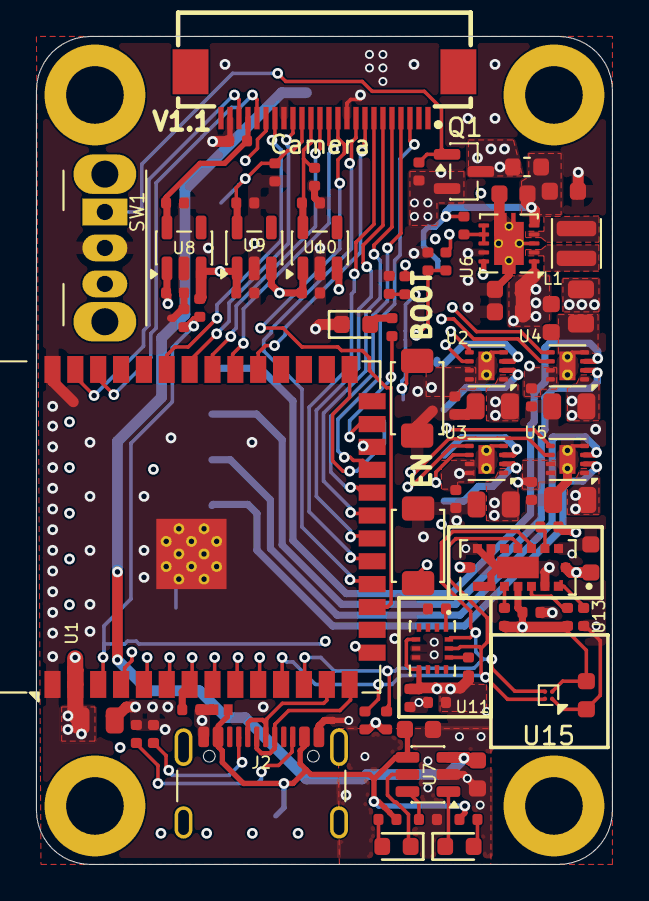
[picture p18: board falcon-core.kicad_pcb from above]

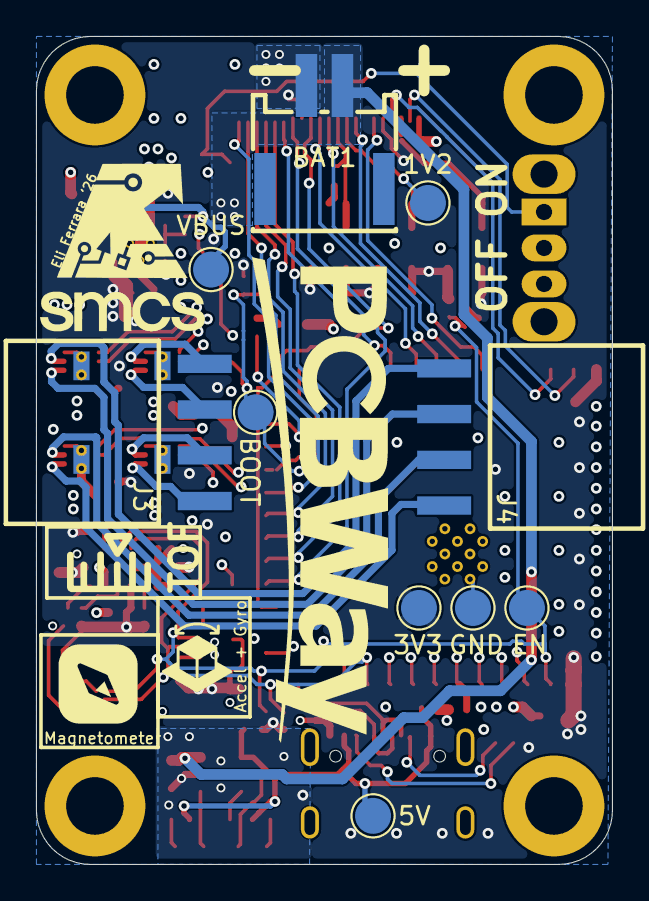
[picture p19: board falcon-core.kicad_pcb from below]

Board: 4 copper layers, 32.0 x 46.0 mm, 93 parts (10 on the bottom side), 65 nets.

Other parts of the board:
C30#2: 100nF; C_0402

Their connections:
GND: C30#2.2; also elsewhere on the board

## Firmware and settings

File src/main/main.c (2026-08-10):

/*
 * Falcon Core – autonomous blimp flight controller firmware.
 *
 * app_main brings up every subsystem then launches the FreeRTOS task set that
 * reads sensors, fuses attitude, drives motors, and streams telemetry/video to
 * the laptop dashboard over WiFi.
 */

#include <stdio.h>
#include <string.h>
#include "freertos/FreeRTOS.h"
#include "freertos/task.h"
#include "esp_log.h"
#include "esp_timer.h"
#include "nvs_flash.h"

#include "state.h"
#include "led.h"
#include "wifi.h"
#include "motors.h"
#include "battery.h"
#include "sensors.h"
#include "fusion.h"
#include "magcal.h"
#include "camera.h"
#include "server.h"

static const char *TAG = "falcon";

/* ---- Periodic tasks ----------------------------------------------------- */

static void sensor_task(void *arg)   /* core 0, 50 Hz */
{
    (void)arg;
    TickType_t last = xTaskGetTickCount();
    float accel[3], gyro[3], mag[3];
    while (1) {
        if (sensors_read_imu(accel, gyro)) {
            state_set_imu(accel, gyro);
        }
        if (sensors_read_mag(mag)) {
            state_set_mag(mag);
        }
        vTaskDelayUntil(&last, pdMS_TO_TICKS(20));
    }
}

static void fusion_task(void *arg)   /* core 0, 50 Hz */
{
    (void)arg;
    const float dt = 0.02f;
    TickType_t last = xTaskGetTickCount();
    while (1) {
        falcon_state_t s;
        state_snapshot(&s);
        /* Heading uses the calibrated magnetometer; telemetry still reports the
         * raw vector so the dashboard can (re)compute calibration from it. */
        float mag_cal[3];
        magcal_apply(s.mag, mag_cal);
        float roll, pitch, yaw, heading;
        fusion_update(s.accel, s.gyro, mag_cal, dt, &roll, &pitch, &yaw, &heading);
        state_set_attitude(roll, pitch, yaw, heading);
        vTaskDelayUntil(&last, pdMS_TO_TICKS(20));
    }
}

static void motor_task(void *arg)    /* core 0, 50 Hz */
{
    (void)arg;
    TickType_t last = xTaskGetTickCount();
    while (1) {
        float cmd[4], out[4];
        state_get_motor_cmd(cmd);
        motors_apply(cmd, out);
        state_set_motor_output(out);
        vTaskDelayUntil(&last, pdMS_TO_TICKS(20));
    }
}

static void tof_task(void *arg)      /* core 0, 10 Hz */
{
    (void)arg;
    TickType_t last = xTaskGetTickCount();
    while (1) {
        uint16_t mm;
        uint16_t grid[TOF_GRID_ZONES];
        if (sensors_read_tof(&mm, grid)) {
            state_set_tof(mm, grid);
        }
        vTaskDelayUntil(&last, pdMS_TO_TICKS(100));
    }
}

static void battery_task(void *arg)  /* core 0, 1 Hz */
{
    (void)arg;
    TickType_t last = xTaskGetTickCount();
    while (1) {
        float v;
        uint8_t pct;
        battery_read(&v, &pct);
        state_set_battery(v, pct);
        vTaskDelayUntil(&last, pdMS_TO_TICKS(1000));
    }
}

static void telemetry_task(void *arg)  /* core 0, 20 Hz */
{
    (void)arg;
    static char json[1400];
    TickType_t last = xTaskGetTickCount();
    while (1) {
        falcon_state_t s;
        state_snapshot(&s);
        magcal_t mc;
        magcal_get(&mc);
        uint32_t ts = (uint32_t)(esp_timer_get_time() / 1000);

        /* Flatten the 8x8 ToF grid into a JSON array (row-major, mm).
         * 64 zones × up to 5 chars ("4000,") plus brackets and NUL. */
        char grid_str[352];
        int gp = 0;
        grid_str[gp++] = '[';
        for (int i = 0; i < TOF_GRID_ZONES; i++) {
            gp += snprintf(grid_str + gp, sizeof(grid_str) - gp,
                           "%s%u", i ? "," : "", s.tof_grid[i]);
        }
        grid_str[gp++] = ']';
        grid_str[gp] = '\0';

        int n = snprintf(json, sizeof(json),
            "{\"type\":\"telemetry\",\"ts\":%lu,"
            "\"imu\":{\"ax\":%.3f,\"ay\":%.3f,\"az\":%.3f,"
            "\"gx\":%.3f,\"gy\":%.3f,\"gz\":%.3f},"
            "\"mag\":{\"x\":%.2f,\"y\":%.2f,\"z\":%.2f,\"heading\":%.1f},"
            "\"magcal\":{\"ox\":%.2f,\"oy\":%.2f,\"oz\":%.2f,"
            "\"sx\":%.4f,\"sy\":%.4f,\"sz\":%.4f},"
            "\"tof\":{\"distance_mm\":%u,\"grid\":%s},"
            "\"battery\":{\"voltage\":%.3f,\"percent\":%u},"
            "\"wifi\":{\"rssi\":%d},"
            "\"attitude\":{\"roll\":%.1f,\"pitch\":%.1f,\"yaw\":%.1f},"
            "\"motors\":{\"m1\":%.2f,\"m2\":%.2f,\"m3\":%.2f,\"m4\":%.2f}}",
            (unsigned long)ts,
            s.accel[0], s.accel[1], s.accel[2],
            s.gyro[0], s.gyro[1], s.gyro[2],
            s.mag[0], s.mag[1], s.mag[2], s.heading_deg,
            mc.offset[0], mc.offset[1], mc.offset[2],
            mc.scale[0], mc.scale[1], mc.scale[2],
            s.altitude_mm, grid_str,
            s.battery_voltage, s.battery_percent,
            wifi_rssi(),
            s.roll, s.pitch, s.yaw,
            s.motor_output[0], s.motor_output[1],
            s.motor_output[2], s.motor_output[3]);

        if (n > 0) {
            server_ws_broadcast(json, (size_t)n);
        }
        vTaskDelayUntil(&last, pdMS_TO_TICKS(50));
    }
}

/* ---- app_main ----------------------------------------------------------- */

void app_main(void)
{
    ESP_LOGI(TAG, "Falcon Core booting");

    esp_err_t nvs = nvs_flash_init();
    if (nvs == ESP_ERR_NVS_NO_FREE_PAGES || nvs == ESP_ERR_NVS_NEW_VERSION_FOUND) {
        ESP_ERROR_CHECK(nvs_flash_erase());
        ESP_ERROR_CHECK(nvs_flash_init());
    }

    state_init();
    magcal_init();
    led_init();
    led_set_mode(LED_CONNECTING);

    /* Camera first: its 20 MHz XCLK is generated by LEDC, and on the ESP32-S3
     * all LEDC low-speed timers share one clock source. Letting the camera
     * (the stricter consumer) pick that source before the 20 kHz motor PWM
     * guarantees a source fast enough for both. */
    if (camera_init() != ESP_OK) {
        ESP_LOGW(TAG, "camera unavailable; stream disabled");
    }

    motors_init();
    battery_init();
    fusion_init();

    if (sensors_init() != ESP_OK) {
        ESP_LOGE(TAG, "sensor init error");
    }

    wifi_init_sta();
    if (wifi_wait_connected(30000)) {
        ESP_LOGI(TAG, "WiFi up. Dashboard: http://%s/", wifi_ip_str());
        led_set_mode(LED_RUNNING);
    } else {
        ESP_LOGE(TAG, "WiFi connect timeout; continuing, will keep retrying");
        led_set_mode(LED_ERROR);
    }

    ESP_ERROR_CHECK(server_start());

    /* Tasks: (name, stack, prio, core) per the firmware architecture table. */
    xTaskCreatePinnedToCore(sensor_task,    "sensor",    4096, NULL, 5, NULL, 0);
    xTaskCreatePinnedToCore(fusion_task,    "fusion",    4096, NULL, 5, NULL, 0);
    xTaskCreatePinnedToCore(motor_task,     "motor",     3072, NULL, 6, NULL, 0);
    xTaskCreatePinnedToCore(tof_task,       "tof",       4096, NULL, 4, NULL, 0);
    xTaskCreatePinnedToCore(battery_task,   "battery",   3072, NULL, 3, NULL, 0);
    xTaskCreatePinnedToCore(telemetry_task, "telemetry", 4096, NULL, 4, NULL, 0);

    ESP_LOGI(TAG, "Falcon Core running");
}

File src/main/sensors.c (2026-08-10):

#include "sensors.h"
#include <string.h>
#include <math.h>
#include "esp_log.h"
#include "esp_rom_sys.h"
#include "freertos/FreeRTOS.h"
#include "freertos/task.h"
#include "driver/i2c_master.h"

#include "bmi270.h"
#include "vl53l5cx_api.h"

static const char *TAG = "sensors";

/* ---- Bus / pinout ------------------------------------------------------- */
#define I2C_PORT      I2C_NUM_0
#define I2C_SDA_GPIO  8
#define I2C_SCL_GPIO  18
#define I2C_FREQ_HZ   400000

#define ADDR_BMI270   0x68
#define ADDR_MMC5633  0x30
#define ADDR_VL53L5CX 0x29

static i2c_master_bus_handle_t s_bus;
static i2c_master_dev_handle_t s_bmi_dev;
static i2c_master_dev_handle_t s_mmc_dev;
static i2c_master_dev_handle_t s_tof_dev;

static bool s_imu_ok, s_mag_ok, s_tof_ok;

/* ---- BMI270 ------------------------------------------------------------- */
static struct bmi2_dev s_bmi;

static BMI2_INTF_RETURN_TYPE bmi2_i2c_read(uint8_t reg, uint8_t *data,
                                           uint32_t len, void *intf)
{
    i2c_master_dev_handle_t dev = (i2c_master_dev_handle_t)intf;
    return i2c_master_transmit_receive(dev, &reg, 1, data, len, 1000) == ESP_OK
               ? BMI2_OK : BMI2_E_COM_FAIL;
}

static BMI2_INTF_RETURN_TYPE bmi2_i2c_write(uint8_t reg, const uint8_t *data,
                                            uint32_t len, void *intf)
{
    i2c_master_dev_handle_t dev = (i2c_master_dev_handle_t)intf;
    uint8_t buf[260];
    if (len > sizeof(buf) - 1) {
        return BMI2_E_COM_FAIL;
    }
    buf[0] = reg;
    memcpy(&buf[1], data, len);
    return i2c_master_transmit(dev, buf, len + 1, 1000) == ESP_OK
               ? BMI2_OK : BMI2_E_COM_FAIL;
}

static void bmi2_delay_us(uint32_t period, void *intf)
{
    (void)intf;
    esp_rom_delay_us(period);
}

static esp_err_t bmi270_setup(void)
{
    s_bmi.intf = BMI2_I2C_INTF;
    s_bmi.read = bmi2_i2c_read;
    s_bmi.write = bmi2_i2c_write;
    s_bmi.delay_us = bmi2_delay_us;
    s_bmi.intf_ptr = s_bmi_dev;
    s_bmi.read_write_len = 240;
    s_bmi.config_file_ptr = NULL;   /* use the driver's built-in config blob */

    int8_t rslt = bmi270_init(&s_bmi);
    if (rslt != BMI2_OK) {
        ESP_LOGE(TAG, "bmi270_init failed (%d)", rslt);
        return ESP_FAIL;
    }

    struct bmi2_sens_config cfg[2];
    cfg[0].type = BMI2_ACCEL;
    cfg[1].type = BMI2_GYRO;
    if (bmi2_get_sensor_config(cfg, 2, &s_bmi) != BMI2_OK) {
        return ESP_FAIL;
    }

    cfg[0].cfg.acc.odr = BMI2_ACC_ODR_100HZ;
    cfg[0].cfg.acc.range = BMI2_ACC_RANGE_2G;
    cfg[0].cfg.acc.bwp = BMI2_ACC_NORMAL_AVG4;
    cfg[0].cfg.acc.filter_perf = BMI2_PERF_OPT_MODE;

    cfg[1].cfg.gyr.odr = BMI2_GYR_ODR_100HZ;
    cfg[1].cfg.gyr.range = BMI2_GYR_RANGE_500;
    cfg[1].cfg.gyr.bwp = BMI2_GYR_NORMAL_MODE;
    cfg[1].cfg.gyr.filter_perf = BMI2_PERF_OPT_MODE;
    cfg[1].cfg.gyr.noise_perf = BMI2_POWER_OPT_MODE;

    if (bmi2_set_sensor_config(cfg, 2, &s_bmi) != BMI2_OK) {
        return ESP_FAIL;
    }

    uint8_t sens[2] = { BMI2_ACCEL, BMI2_GYRO };
    if (bmi2_sensor_enable(sens, 2, &s_bmi) != BMI2_OK) {
        return ESP_FAIL;
    }

    ESP_LOGI(TAG, "BMI270 ready (±2g, ±500dps, 100Hz)");
    return ESP_OK;
}

bool sensors_read_imu(float accel[3], float gyro[3])
{
    if (!s_imu_ok) {
        return false;
    }
    struct bmi2_sens_data data;
    if (bmi2_get_sensor_data(&data, &s_bmi) != BMI2_OK) {
        return false;
    }
    /* ±2g over int16 -> m/s^2 ; ±500dps over int16 -> deg/s */
    const float acc_scale = (2.0f / 32768.0f) * 9.80665f;
    const float gyr_scale = 500.0f / 32768.0f;
    accel[0] = data.acc.x * acc_scale;
    accel[1] = data.acc.y * acc_scale;
    accel[2] = data.acc.z * acc_scale;
    gyro[0] = data.gyr.x * gyr_scale;
    gyro[1] = data.gyr.y * gyr_scale;
    gyro[2] = data.gyr.z * gyr_scale;
    return true;
}

/* ---- MMC5633NJL --------------------------------------------------------- */
#define MMC_REG_XOUT0   0x00
#define MMC_REG_CTRL0   0x1B
#define MMC_REG_CTRL1   0x1C
#define MMC_REG_CTRL2   0x1D
#define MMC_REG_ODR     0x1A
#define MMC_REG_PRODID  0x39
#define MMC_PRODUCT_ID  0x10

#define MMC_CTRL0_TM_M       0x01
#define MMC_CTRL0_SET        0x08
#define MMC_CTRL0_RESET      0x10
#define MMC_CTRL0_AUTO_SR    0x20
#define MMC_CTRL0_CMM_FREQ   0x80
#define MMC_CTRL1_SW_RST     0x80
#define MMC_CTRL2_CMM_EN     0x10

static esp_err_t mmc_write(uint8_t reg, uint8_t val)
{
    uint8_t b[2] = { reg, val };
    return i2c_master_transmit(s_mmc_dev, b, 2, 1000);
}

static esp_err_t mmc_read(uint8_t reg, uint8_t *buf, size_t len)
{
    return i2c_master_transmit_receive(s_mmc_dev, &reg, 1, buf, len, 1000);
}

static esp_err_t mmc5633_setup(void)
{
    uint8_t id = 0;
    if (mmc_read(MMC_REG_PRODID, &id, 1) != ESP_OK || id != MMC_PRODUCT_ID) {
        ESP_LOGE(TAG, "MMC5633 product id mismatch (0x%02x)", id);
        return ESP_FAIL;
    }

    mmc_write(MMC_REG_CTRL1, MMC_CTRL1_SW_RST);  /* software reset */
    vTaskDelay(pdMS_TO_TICKS(20));

    mmc_write(MMC_REG_CTRL0, MMC_CTRL0_SET);     /* SET to align magnetics */
    vTaskDelay(pdMS_TO_TICKS(1));
    mmc_write(MMC_REG_CTRL0, MMC_CTRL0_RESET);   /* RESET */
    vTaskDelay(pdMS_TO_TICKS(1));

    mmc_write(MMC_REG_ODR, 50);                  /* 50 Hz output rate */
    /* Apply ODR for continuous mode + automatic SET/RESET each measurement. */
    mmc_write(MMC_REG_CTRL0, MMC_CTRL0_CMM_FREQ | MMC_CTRL0_AUTO_SR);
    mmc_write(MMC_REG_CTRL2, MMC_CTRL2_CMM_EN);  /* start continuous mode */

    ESP_LOGI(TAG, "MMC5633 ready (continuous 50Hz, auto SET/RESET)");
    return ESP_OK;
}

bool sensors_read_mag(float mag[3])
{
    if (!s_mag_ok) {
        return false;
    }
    uint8_t b[9];
    if (mmc_read(MMC_REG_XOUT0, b, 9) != ESP_OK) {
        return false;
    }
    /* 20-bit unsigned, null field at 2^19. 16384 counts/Gauss -> uT. */
    int32_t x = ((int32_t)b[0] << 12) | ((int32_t)b[1] << 4) | (b[6] >> 4);
    int32_t y = ((int32_t)b[2] << 12) | ((int32_t)b[3] << 4) | (b[7] >> 4);
    int32_t z = ((int32_t)b[4] << 12) | ((int32_t)b[5] << 4) | (b[8] >> 4);
    const int32_t center = 1 << 19;
    const float scale = 100.0f / 16384.0f;   /* Gauss->uT over counts/Gauss */
    mag[0] = (x - center) * scale;
    mag[1] = (y - center) * scale;
    mag[2] = (z - center) * scale;
    return true;
}

/* ---- VL53L5CX ----------------------------------------------------------- */
static VL53L5CX_Configuration s_tof;
/* Center zone index for an 8x8 grid (zones 0..63, row-major). The true center
 * falls between 27/28/35/36; 27 (row 3, col 3) is the conventional pick. */
#define TOF_CENTER_ZONE 27
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

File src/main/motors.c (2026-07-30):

#include "motors.h"
#include <math.h>
#include "driver/ledc.h"
#include "driver/gpio.h"
#include "esp_log.h"

static const char *TAG = "motors";

#define LEDC_MODE        LEDC_LOW_SPEED_MODE
#define LEDC_TIMER       LEDC_TIMER_0
#define LEDC_FREQ_HZ     20000
#define LEDC_RES         LEDC_TIMER_10_BIT
#define MAX_DUTY         ((1 << 10) - 1)   /* 1023 */

/* Safety cap on duty during bench testing: 0.0 .. 1.0 */
#define MOTOR_MAX_DUTY_FRAC 0.5f

/*
 * Physical motor layout (viewed from above, nose forward):
 *
 *     left                 right
 *   M1 (forward) ....... M3 (forward)
 *   M2 (vertical) ...... M4 (vertical)
 *
 * Single-channel bidirectional drive: each DRV8212P has IN1 on its own LEDC
 * channel (0..3 on timer 0) and IN2 as a plain GPIO used as a direction pin.
 * Four channels total, leaving channels 4..7 free — the camera XCLK (timer 1 /
 * channel 6) no longer collides, so motors and camera run at the same time.
 */
typedef struct { int in1; int in2; } motor_pins_t;

/* PCB pin map (IN1 is PWM'd, IN2 is the direction GPIO). */
static const motor_pins_t s_pins[MOTOR_COUNT] = {
    { 5,  4  },   /* M1 forward,  left  (wired to former M3 pins) */
    { 3,  17 },   /* M2 vertical, left  */
    { 47, 6  },   /* M3 forward,  right (wired to former M1 pins) */
    { 15, 16 },   /* M4 vertical, right */
};

/* Per-motor spin polarity (+1 normal, -1 reversed) to correct wiring so a
 * positive command always spins CW as commanded. M3 is reversed in hardware. */
static const float s_polarity[MOTOR_COUNT] = { 1.0f, 1.0f, -1.0f, 1.0f };

/* Motor i drives LEDC channel i on its IN1 pin. */
static inline ledc_channel_t ch(int m) { return (ledc_channel_t)m; }

static void set_duty(ledc_channel_t c, uint32_t duty)
{
    ledc_set_duty(LEDC_MODE, c, duty);
    ledc_update_duty(LEDC_MODE, c);
}

void motors_init(void)
{
    ledc_timer_config_t tcfg = {
        .speed_mode = LEDC_MODE,
        .timer_num = LEDC_TIMER,
        .duty_resolution = LEDC_RES,
        .freq_hz = LEDC_FREQ_HZ,
        .clk_cfg = LEDC_AUTO_CLK,
    };
    ESP_ERROR_CHECK(ledc_timer_config(&tcfg));

    for (int m = 0; m < MOTOR_COUNT; m++) {
        /* IN1: PWM channel. */
        ledc_channel_config_t c1 = {
            .speed_mode = LEDC_MODE, .timer_sel = LEDC_TIMER,
            .channel = ch(m), .gpio_num = s_pins[m].in1,
            .duty = 0, .hpoint = 0, .intr_type = LEDC_INTR_DISABLE,
        };
        ESP_ERROR_CHECK(ledc_channel_config(&c1));

        /* IN2: plain GPIO used as the direction pin (LOW = forward/CW). */
        gpio_config_t io = {
            .pin_bit_mask = 1ULL << s_pins[m].in2,
            .mode = GPIO_MODE_OUTPUT,
            .pull_up_en = GPIO_PULLUP_DISABLE,
            .pull_down_en = GPIO_PULLDOWN_DISABLE,
            .intr_type = GPIO_INTR_DISABLE,
        };
        ESP_ERROR_CHECK(gpio_config(&io));
        gpio_set_level(s_pins[m].in2, 0);
    }

    ESP_LOGI(TAG, "LEDC ready: M1-M4 bidirectional @ %d Hz, duty cap %.0f%%",
             LEDC_FREQ_HZ, MOTOR_MAX_DUTY_FRAC * 100.0f);
}

static float clampf(float v, float lo, float hi)
{
    return v < lo ? lo : (v > hi ? hi : v);
}

void motors_apply(const float cmd[MOTOR_COUNT], float out[MOTOR_COUNT])
{
    for (int m = 0; m < MOTOR_COUNT; m++) {
        float c = clampf(cmd[m] * s_polarity[m], -1.0f, 1.0f);
        out[m] = c;

        /* Average output magnitude (0 .. cap). */
        float mag = fabsf(c) * MOTOR_MAX_DUTY_FRAC;

        if (c >= 0.0f) {                 /* CW: forward, fast decay */
            gpio_set_level(s_pins[m].in2, 0);
            set_duty(ch(m), (uint32_t)(mag * MAX_DUTY));
        } else {                         /* CCW: reverse, drive on IN1-low */
            gpio_set_level(s_pins[m].in2, 1);
            set_duty(ch(m), (uint32_t)((1.0f - mag) * MAX_DUTY));
        }
    }
}

void motors_stop(void)
{
    for (int m = 0; m < MOTOR_COUNT; m++) {
        gpio_set_level(s_pins[m].in2, 0);
        set_duty(ch(m), 0);
    }
}

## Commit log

2026-05-12 add hardware design + preliminary readme
    [.step, BGA9_BMM350_BOS.step, BMI270_BOS.step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]
2026-07-02 add first round of software
    [falcon-core.kicad_pcb, falcon-core.kicad_sch, falcon-core.recovered.2026-05-14_083859.kicad_sch]
2026-07-30 Refactor code structure for improved readability and maintainability
    [falcon-core.kicad_pcb, falcon-core.kicad_sch]
2026-07-30 Add mounting offset to heading calculation in fusion update
2026-08-01 Add scripts for battery monitoring and firmware flashing
